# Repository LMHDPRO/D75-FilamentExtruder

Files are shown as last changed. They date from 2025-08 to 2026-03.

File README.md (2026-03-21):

<div align="center">

```
██████╗  ██████╗ ██╗   ██╗ ██████╗ ██╗      █████╗ ███████╗███╗███████╗
██╔══██╗██╔═══██╗██║   ██║██╔════╝ ██║     ██╔══██╗██╔════╝ ██║██╔════╝
██║  ██║██║   ██║██║   ██║██║  ███╗██║     ███████║███████╗╚██║███████╗
██║  ██║██║   ██║██║   ██║██║   ██║██║     ██╔══██║╚════██║ ██║╚════██║
██████╔╝╚██████╔╝╚██████╔╝╚██████╔╝███████╗██║  ██║███████║ ██║███████║
╚═════╝  ╚═════╝  ╚═════╝  ╚═════╝ ╚══════╝╚═╝  ╚═╝╚══════╝ ╚═╝╚══════╝
```

# Filament Extruder Controller

**ESP32 DualCore · FreeRTOS · PID Temperature · Dual TB6600**

*Reduce PP filament — 2.4 mm → 1.75 mm for 3D printing*

---







</div>

---

## ¿Qué es esto?

**Douglas75** es un controlador open-source para una extrusora de filamento, desarrollado originalmente en el marco de un **Practicum** universitario para reducir el diámetro de filamento fabricado artesanalmente. El diseño nació con polipropileno (PP) de **2.4 mm → 1.75 mm**, pero el sistema es compatible con cualquier tipo de filamento termoplástico que requiera un proceso de reducción controlada de diámetro.

El sistema corre en un **ESP32 con FreeRTOS dual-core** — un núcleo dedicado al control PID de temperatura y otro a la interfaz de usuario. Incluye un **panel de control Tkinter** para operación desde PC vía USB serial.

---

## Características

| | Función | Detalle |
|---|---|---|
| 🌡️ | Control temperatura | PID con NTC 100K genérico Ender3 (β = 3950) |
| 🔥 | Calefactor | MOSFET IRLZ44N, PWM 5 kHz vía LEDC |
| 💨 | Ventilador | MOSFET IRLZ44N, PWM proporcional AUTO o manual OFF |
| ⚙️ | Motores | 2× NEMA17 full-step, drivers TB6600, enable compartido |
| 🖥️ | LCD | I2C 20×4 @ 0x27, menú completo con encoder KY-040 |
| 💻 | GUI PC | Tkinter dark mode + gráfica temperatura en tiempo real |
| 🧵 | Estimación | Contador de filamento procesado (mm y gramos) |
| ⚡ | Arquitectura | FreeRTOS — Core 0: PID · Core 1: HMI |

---

## Hardware

### Bill of Materials (BOM)

| # | Categoría | Componente | Modelo / Especificación | Qty |
|:---:|---|---|---|:---:|
| 1 | 🧠 MCU | Microcontrolador | ESP32 Development Board | 1 |
| 2 | 🔥 Calefactor | Hotend completo | 40W 12V Ceramic Cartridge Heater + NTC 100K Thermistor | 1 |
| 3 | 🔩 Boquilla | Nozzle | MK8 0.4 mm Nozzle | 1 |
| 4 | ⚙️ Extrusión | Extrusor | Creality MK8 Extruder | 1 |
| 5 | ⚙️ Motor | Motor paso a paso | NEMA17 Stepper Motor | 2 |
| 6 | ⚙️ Driver | Driver motor | TB6600 Stepper Motor Driver | 2 |
| 7 | 🔧 Soporte | Montura motor | NEMA Motor Mount | 2 |
| 8 | 🖥️ Pantalla | Pantalla LCD | 20×4 LCD Screen I2C | 1 |
| 9 | 🎛️ Entrada | Encoder rotatorio | KY-040 Rotary Encoder | 1 |
| 10 | 🧵 Sensor | Sensor de filamento | Filament Runout Sensor | 1 |
| 11 | ⚡ Regulador | Regulador voltaje | L7805CV 5V Voltage Regulator (TO-220) | 1 |
| 12 | ⚡ MOSFET | MOSFET N-Channel | IRFL44N N-Channel MOSFET | 2 |
| 13 | 🔩 Rodamientos | Rodamiento | 608ZZ Bearing | 4 |
| 14 | 💨 Ventilador | Fan | 4010 Fan 12V | 1 |
| 15 | 🟫 PCB | Placa base | 15×15 cm Single-Sided Phenolic Board | 1 |
| 16 | 🔌 Conectores | Pin header | 36-pin Single Row Pin Header (2.54 mm) | 1 |
| 17 | 🔌 Conectores | Female header | 10-pin Female Header (2.54 mm) | 2 |
| 18 | 🔌 Conectores | Terminales | 2-Pin Green Screw Terminals | 6 |
| 19 | 🔋 Capacitores | Condensador electrolítico | 100 µF | 2 |
| 20 | 🔋 Capacitores | Condensador cerámico | 100 nF | 2 |
| 21 | 🔩 Tornillería | Tornillos Allen | M2, M3 & M4 Socket Head Screws (surtido) | — |

### Mapa de pines ESP32

| GPIO | Señal | Tipo |
|---|---|---|
| `18` | OUTA encoder (CLK) | Input interrupt |
| `19` | OUTB encoder (DT) | Input interrupt |
| `5` | SW encoder | Input PULLUP |
| `34` | Termistor NTC | ADC1_CH6 |
| `25` | MOSFET calefactor | PWM LEDC ch0 |
| `23` | MOSFET ventilador | PWM LEDC ch1 |
| `26` | STEP Motor 1 | Output |
| `27` | DIR Motor 1 | Output |
| `4` | STEP Motor 2 | Output |
| `2` | DIR Motor 2 | Output |
| `13` | EN_Driver | Output |
| `21` | SDA LCD | I2C |
| `22` | SCL LCD | I2C |

> ⚠️ **Pines prohibidos:** GPIO 0, 6–11 (flash interno), 12, 15

### Circuito divisor NTC

```
3.3V
 │
[4.7 KΩ]  ← R7 pull-up
 │
 ├──── GPIO34 ──────────────── net: Thermistor_GPIO34
 │
 ├──── 100 nF cerámico  ┐ en paralelo
 ├──── 10 µF electrolítico ┘
 │
[NTC 100K]  ← cable vía J3 terminal block
 │
GND
```

### Circuito calefactor

```
GPIO25 ──[10 Ω]──→ Gate IRLZ44N
                    Drain  → Calefactor DC 12V (−)
                    Source → GND

[10 KΩ] entre Gate y GND   ← pull-down, seguro durante boot
LED + [1.8 KΩ] en paralelo ← indicador visual de activación
```

### Alimentación dual USB + 12V

```
12V (fuente principal)
 ├── Buck LM2596 → 5V → VIN ESP32
 ├── TB6600 VMOT  (+ condensador 100 µF entre VMOT y GND)
 └── Calefactor DC (vía MOSFET)

USB-C ESP32 → PC  (serial Tkinter GUI)
✓ Coexistencia segura — diodo Schottky en DevKit aísla USB de VIN
```

---

## Menú LCD

```
ARRANQUE
  └── Splash 2s
        └── MENÚ PRINCIPAL
              ├── ► PRE-CALENTAR ──→ Calienta a 150 °C
              │                       Barra de progreso
              │                       Auto-arranca al llegar
              └── ► CONFIGURAR
                    ├── VELOCIDAD DRV 1   (0–300 RPM, paso 10)
                    ├── VELOCIDAD DRV 2   (0–300 RPM, paso 10)
                    ├── TEMPERATURA       (20–260 °C, paso 1)
                    └── VENTILADOR        (AUTO / OFF)

PANTALLA CORRIENDO:
  ┌────────────────────┐
  │ T:160.5C  SP:160C  │
  │ D1:100RPM D2:100RP │
  │ PWM:127   FAN:AUTO │
  │ CORRIENDO Lng=STOP │
  └────────────────────┘
```

**Controles encoder KY-040:**

| Acción | Función |
|---|---|
| Girar | Navegar menú / cambiar valor |
| Presión corta | Seleccionar / confirmar |
| Presión larga >700 ms | Volver / STOP de emergencia |

---

## Protocolo Serial

**115200 baud, 8N1**

### ESP32 → PC (cada 100 ms)

```
T:160.5,S:160,D1:100,D2:100,P:127,F:64,RUN:1
```

| Campo | Descripción |
|---|---|
| `T` | Temperatura real (°C) — o `ERR` si falla el sensor |
| `S` | Setpoint temperatura |
| `D1` / `D2` | RPM motores 1 y 2 |
| `P` | PWM calefactor (0–255) |
| `F` | PWM ventilador (0–255) |
| `RUN` | Estado extrusión `0`/`1` |

### PC → ESP32

| Comando | Descripción |
|---|---|
| `ST:165` | Cambiar setpoint temperatura |
| `SD1:100` | Cambiar RPM Motor 1 |
| `SD2:120` | Cambiar RPM Motor 2 |
| `SF:1` / `SF:0` | Ventilador AUTO / OFF |
| `RUN` | Iniciar extrusión |
| `STOP` | Detener extrusión |
| `JOG1:1` / `JOG1:0` | Motor 1 manual ON/OFF |
| `JOG2:1` / `JOG2:0` | Motor 2 manual ON/OFF |
| `EN:1` / `EN:0` | Habilitar / deshabilitar ambos TB6600 |

---

## Instalación

### Firmware ESP32

**1. Instalar PlatformIO:**

Instala la extensión [PlatformIO IDE](https://platformio.org/install/ide?install=vscode) para VS Code.

**2. Clonar y abrir el proyecto:**

```bash
git clone https://github.com/LMHDPRO/D75-FilamentExtruder.git
cd D75-FilamentExtruder
code .   # abrir en VS Code con PlatformIO
```

**3. Las dependencias se instalan automáticamente** desde `platformio.ini`:

```ini
[env:esp32dev]
platform  = espressif32
board     = esp32dev
framework = arduino
lib_deps  =
    mathertel/RotaryEncoder
    br3ttb/PID
    waspinator/AccelStepper
    marcoschwartz/LiquidCrystal_I2C
```

**4. Subir el firmware:**

Botón **Upload** (→) en la barra de PlatformIO, o:

```bash
pio run --target upload
```

> Si no entra en modo flash automáticamente, mantén presionado el botón **BOOT** del DevKit mientras sube.

**5. Verificar en Serial Monitor (115200 baud):**

```
T:25.3,S:160,D1:100,D2:100,P:0,F:0,RUN:0   ✓ Sensor OK
T:ERR,S:0,D1:0,D2:0,P:0,F:0,RUN:0          ✗ Revisar NTC o divisor
```

### GUI Python

```bash
pip install pyserial matplotlib
python extrusora_gui.py
```

---

## Arquitectura de software

```
ESP32 — FreeRTOS DualCore
│
├── Core 0  [prioridad 2]  taskPID
│    ├── Leer NTC (promedio 8 muestras)
│    ├── Calcular PID
│    ├── Escribir LEDC calefactor (0–255)
│    ├── Calcular PWM ventilador proporcional
│    └── Enviar telemetría serial cada 100 ms
│
└── Core 1  [prioridad 1]  taskHMI
     ├── Encoder KY-040 via interrupciones
     ├── Máquina de estados LCD (6 estados)
     ├── AccelStepper Motor 1 + Motor 2
     └── Parser comandos serial desde PC

Variables compartidas → protegidas con portMUX_TYPE
```

---

## Calibración

### Temperatura no coincide con la real

Cambiar `NTC_BETA` en `extrusora_esp32.ino`:

| Termistor | β |
|---|---|
| Genérico impresoras 3D (este proyecto) | **3950** |
| Semitec 104GT-2 | 4267 |
| EPCOS B57560G | 3988 |
| Marlin tabla 1 | 4388 |

### Motor gira al revés

```cpp
#define MOTOR_DIR  -1   →   #define MOTOR_DIR  1
```

### Estimación de filamento

Medir el diámetro del rodillo de arrastre con un vernier y actualizar en `extrusora_gui.py`:

```python
DRIVE_DIAM_MM = 11.0   # ← reemplazar con medición real
```

---

## Estructura del repositorio

```
D75-FilamentExtruder/
 ├── firmware/
 │    └── extrusora_esp32.ino      ← código ESP32
 ├── software/
 │    └── extrusora_gui.py         ← panel de control PC
 ├── hardware/
 │    ├── CircuitoESP32.kicad_sch  ← esquemático KiCad
 │    └── CircuitoESP32.kicad_pcb  ← PCB KiCad
 └── README.md
```

---

## Créditos

- [RotaryEncoder](https://github.com/mathertel/RotaryEncoder) — Matthias Hertel
- [Arduino PID Library](https://github.com/br3ttb/Arduino-PID-Library) — Brett Beauregard
- [AccelStepper](https://www.airspayce.com/mikem/arduino/AccelStepper/) — Mike McCauley
- [LiquidCrystal_I2C](https://github.com/marcoschwartz/LiquidCrystal_I2C) — Frank de Brabander

---

## Equipo

<div align="center">

*Proyecto desarrollado en la* **Universidad Anáhuac Mayab** *— Mérida, Yucatán*

<br>

| | Nombre | |
|:---:|:---|:---:|
| 🧑‍💻 | **Skyler Schenck** |  |
| 🧑‍💻 | **Darian Cuellar** |  |
| 🧑‍💻 | **José Pardiñaz** |  |
| 🧑‍💻 | **Douglas Fuentes** |  |
| 🧑‍🔬 | **Gerardo Alonzo** |  |
| 🧑‍🔬 | **Andrés Oliva** |  |

<br>



</div>

---

## Apoya el proyecto

Este proyecto es **open-source bajo licencia MIT** — puedes usarlo, modificarlo y distribuirlo libremente. Si te fue útil y quieres apoyar al creador, puedes conseguir los archivos 3D del modelo físico de la extrusora en Cults3D a precio libre:

<div align="center">



*Los archivos de código son y serán siempre gratuitos. El modelo 3D está disponible en Cults a precio libre — cualquier contribución es bienvenida y apoya el desarrollo continuo.*

</div>

---

## Licencia

MIT License — úsalo, modifícalo y distribúyelo libremente.

---

<div align="center">
<sub>Douglas75 Project · ESP32_Experimental · Made with ☕ in Mérida, MX</sub>
</div>

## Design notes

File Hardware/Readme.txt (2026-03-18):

KICAD 9.0

CREATED & DESIGNED BY JOSÉ PARDIÑAZ AND DOUGLAS FUENTES :)

V2. DARIAN CUELLAR

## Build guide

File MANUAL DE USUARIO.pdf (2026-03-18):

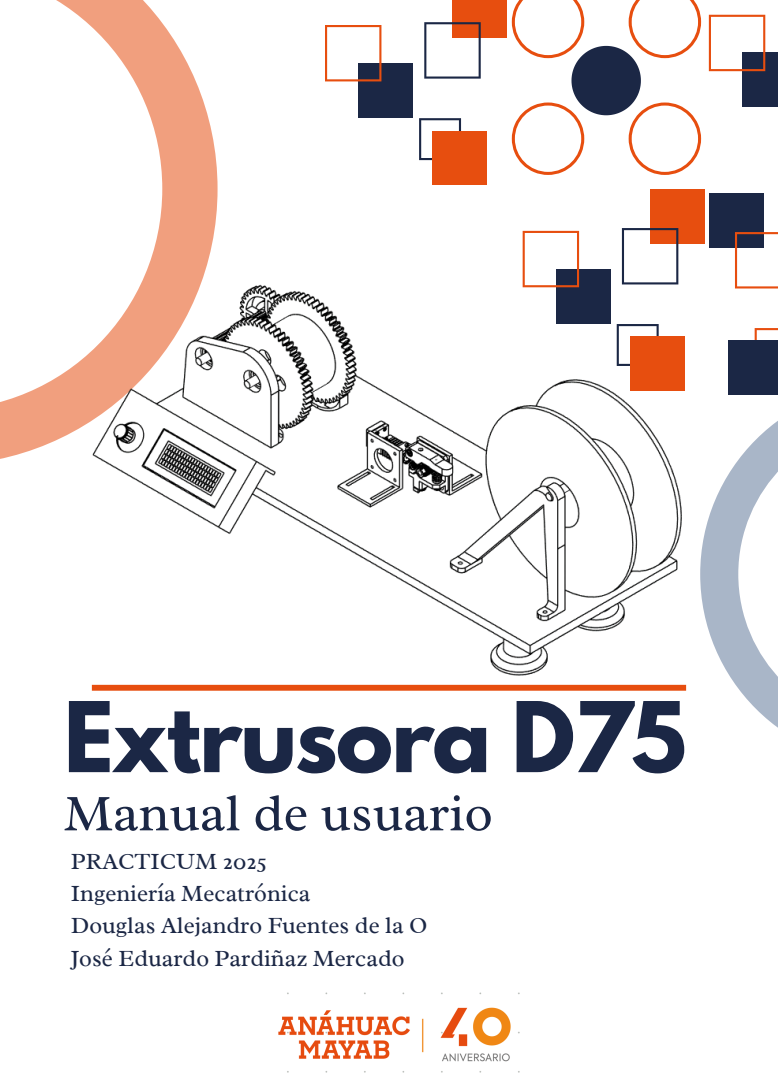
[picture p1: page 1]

Extrusora D75
Manual de usuario

PRACTICUM 2025
Ingeniería Mecatrónica
Douglas Alejandro Fuentes de la O
José Eduardo Pardiñaz Mercado

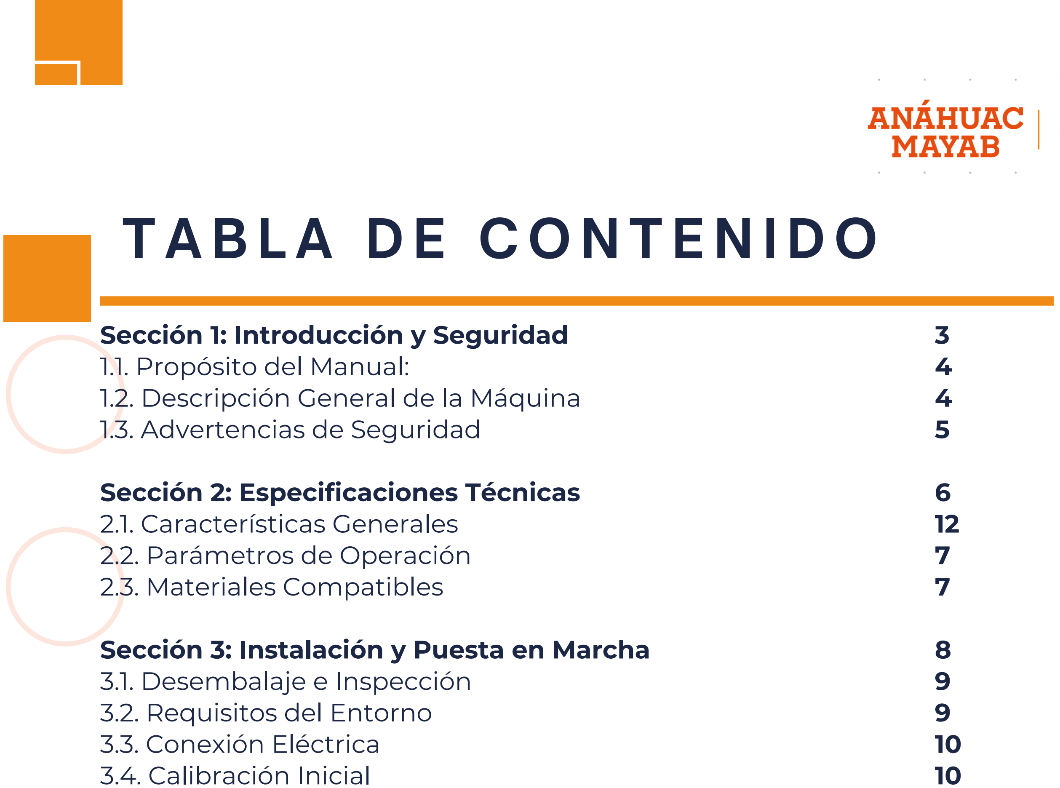
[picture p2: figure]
Sección 1: Introducción y Seguridad 1.1. Propósito del Manual: 1.2. Descripción General de la Máquina 1.3. Advertencias de Seguridad; Sección 2: Especificaciones Técnicas 2.1. Características Generales 2.2. Parámetros de Operación 2.3. Materiales Compatibles; 3.1. Desembalaje e Inspección 3.2. Requisitos del Entorno 3.3. Conexión Eléctrica

Sección 3: Instalación y Puesta en Marcha

3.4. Calibración Inicial

Sección 4: Componentes y Panel de Control
4.1. Diagrama General
4.2. Descripción del Panel de Control

Sección 5: Guía de Operación
5.1. Preparación del Material
5.2. Procedimiento de Encendido
5.3. Proceso de Extrusión
5.4. Procedimiento de Apagado y Purga

Sección 6: Mantenimiento y Limpieza
6.1. Programa de Mantenimiento Preventivo
6.2. Procedimientos de Limpieza
6.3. Procedimientos de Mantenimiento

Sección 7: Solución de Problemas
7.1. Tabla de Fallos Comunes

Sección 8: Anexos Técnicos
A. Diagrama Eléctrico
B. Diseño de PCB
C. Explosión y lista de componentes
D. Firmware del sistema
E. Glosarios de términos
F. Archivos STL

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
# INTRODUCCIÓN Y SEGURIDAD

# S E C C I Ó N 1

## Esta sección inicial presenta la Extrusora D75, explicando

su propósito y las capacidades de reciclaje de filamento.

## Fundamentalmente, establece las advertencias de seguridad más importantes, detallando los riesgos de quemaduras por altas temperaturas, atrapamiento por partes móviles y peligros eléctricos, además de especificar el equipo de protección personal necesario para operar la

máquina de forma segura.

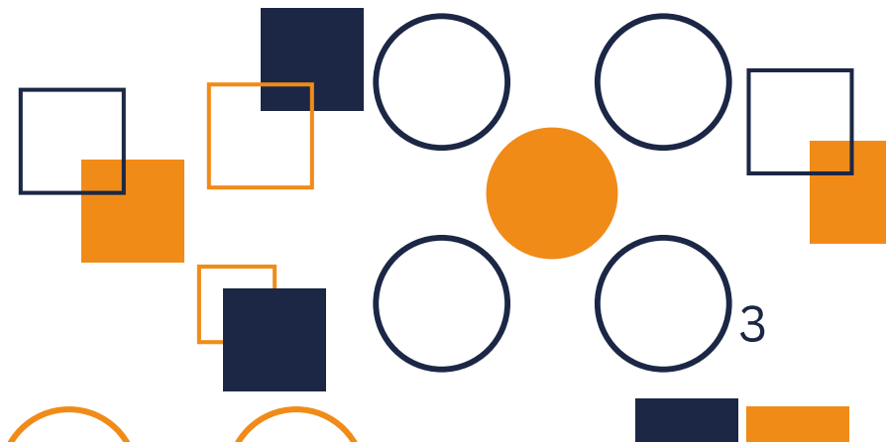
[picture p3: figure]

# 1.1. Propósito de este Manual

# 1.2. Descripción General de la Máquina

Bienvenido a la Extrusora D75. Este manual le proporcionará toda la información necesaria para instalar, operar y mantener su máquina de forma segura y eficiente. Ha sido redactado para guiarlo a través de todas las capacidades del equipo.
Es fundamental leer este documento en su totalidad antes de energizar u operar la extrusora. Guarde este manual en un lugar accesible para futuras consultas.

La Extrusora D75 es una máquina de extrusión de filamento diseñada para ser una herramienta versátil en entornos académicos e de investigación. Su propósito es transformar tramos de plástico en un filamento de alta calidad con un diámetro nominal de 1.75 mm.
Desarrollada con un enfoque en la accesibilidad y la personalización, su construcción de bajo costo y diseño cómodo la convierten en una plataforma ideal para:
Estudiantes y educadores: Para el aprendizaje práctico sobre polímeros y procesos de reciclaje.
Proyectos de investigación: Permitiendo la experimentación con una amplia gama de termoplásticos.
Profesionales y talleres: Para reutilizar material de desecho (impresiones fallidas, soportes) y reducir costos operativos.

Aunque ha sido probada exitosamente con materiales como PET y PP, su diseño permite trabajar con un amplio espectro de polímeros que se ajusten a su rango de temperatura.

# 1.3. Advertencias de Seguridad

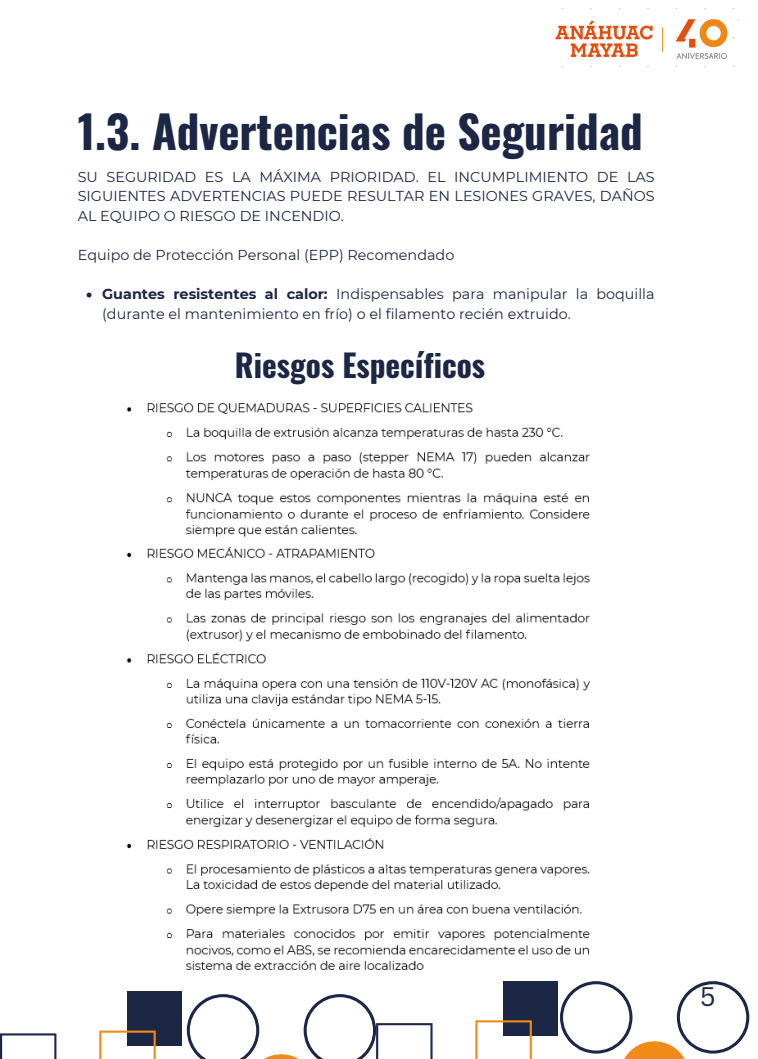
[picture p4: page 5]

SU SEGURIDAD ES LA MÁXIMA PRIORIDAD. EL INCUMPLIMIENTO DE LAS
SIGUIENTES ADVERTENCIAS PUEDE RESULTAR EN LESIONES GRAVES, DAÑOS
AL EQUIPO O RIESGO DE INCENDIO.

Equipo de Protección Personal (EPP) Recomendado

Guantes resistentes al calor: Indispensables para manipular la boquilla
(durante el mantenimiento en frío) o el filamento recién extruido.
Riesgos Específicos

# ESPECIFICACIONES TÉCNICAS

# S E C C I Ó N 2

Aquí se encuentra la ficha técnica completa de la máquina. Este apartado cuantifica las características del equipo, incluyendo sus dimensiones físicas y peso , los parámetros eléctricos como el voltaje de operación y el consumo de potencia , su rendimiento de extrusión con la velocidad y la tolerancia de diámetro , y la lista de

materiales plásticos compatibles que puede procesar.

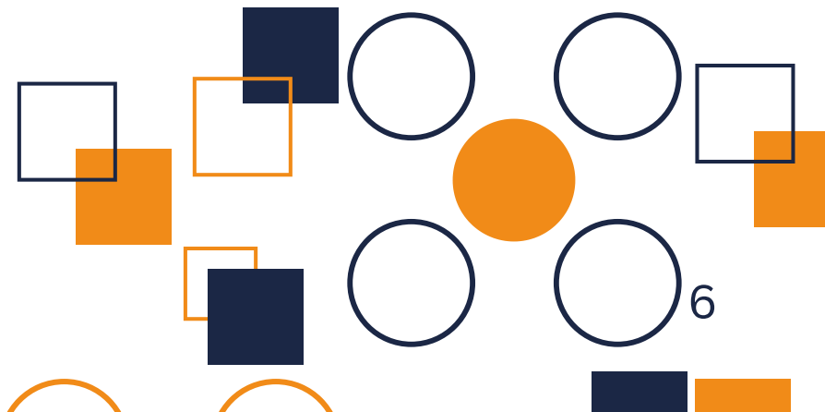
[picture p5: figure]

# 2.1. Características Generales

# 2.3. Materiales Compatibles

Dimensiones (L × An × Al): 540 mm × 155 mm × 435 mm
Peso neto: 1.86 kg
Principio de extrusión: Extrusión térmica mediante sistema de impulsión por engranes.
Sistema de extrusión: Basado en el mecanismo de extrusión de la Creality Ender 3 v1, adaptado para la alimentación y fusión de filamento termoplástico.

El diseño de la Extrusora D75 permite trabajar con una variedad de termoplásticos. A continuación se listan los materiales probados y los potencialmente compatibles.
Materiales Verificados:
PET (Tereftalato de polietileno)
PP (Polipropileno)
Materiales Teóricamente Compatibles:
PLA (Ácido poliláctico)
PETG (Tereftalato de polietileno modificado con glicol)
TPU (Poliuretano termoplástico y otros elastómeros)
HDPE / LDPE (Polietileno de alta y baja densidad)
Nota Importante: La compatibilidad teórica se basa en el rango de temperatura de la máquina. El éxito de la extrusión con estos materiales dependerá de la correcta configuración de los parámetros.

# 2.2. Parámetros de Operación

Eléctricos

Tensión de Alimentación: 110V-120V AC (monofásica). Sistema de Calentamiento: Cartucho calefactor de 12V, 40W. Consumo Máximo de Potencia: 56W

Rendimiento

Temperatura Máxima de Operación: 230 °C (en la boquilla). Diámetro Nominal del Filamento: 1.75 mm
Tolerancia de Diámetro: ±0.04 mm
Velocidad de Extrusión (aprox.): 0.5 metros/minuto.

# INSTALACIÓN Y PUESTA EN MARCHA

# S E C C I Ó N 3

Esta es la guía para el primer uso, que detalla los pasos para preparar la máquina desde que sale de la caja. Cubre el desembalaje, la inspección inicial, los requisitos del entorno de trabajo como la necesidad de una superficie nivelada y ventilada, y el procedimiento correcto para la conexión eléctrica y el encendido inicial seguro del

sistema.

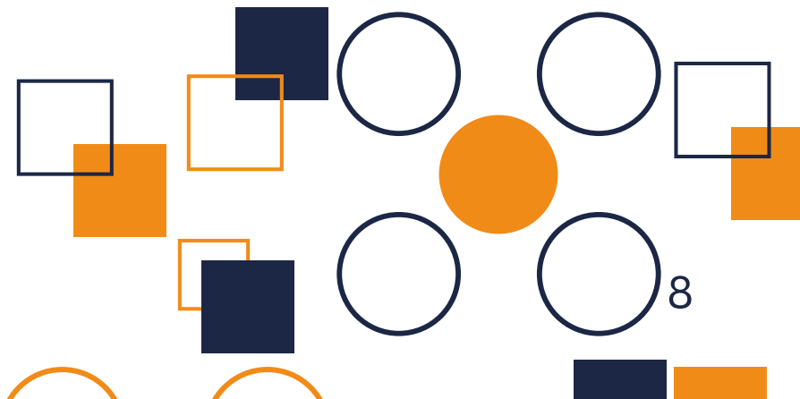
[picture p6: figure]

# 3.1. Desembalaje e Inspección

Inspección visual: Revise la máquina en busca de posibles daños ocurridos durante el transporte. Asegúrese de que todos los componentes estén firmes y en su lugar.
Contenido del paquete:
Unidad principal de la Extrusora D75.
Juego de boquillas de extrusión adicionales.
Cable de alimentación.
Portacarrete.
Montaje del Portacarrete: Fije el portacarrete en su posición designada. Asegúrese de que quede firme y estable para soportar el peso de una bobina de material.

# 3.2. Requisitos del Entorno de Trabajo

Seleccionar un lugar adecuado es clave para la seguridad y la calidad de la extrusión.
Superficie de Trabajo: Coloque la máquina sobre una superficie firme, estable y perfectamente nivelada.
Condiciones Ambientales:
Instale la máquina en un lugar seco y con buena ventilación. Evite a toda costa los ambientes húmedos.
Mantenga la máquina alejada de la luz solar directa y de otras fuentes de calor. El calor excesivo puede afectar tanto a la electrónica como a los materiales (especialmente PLA).
¡Peligro de Incendio! Opere la máquina lejos de cualquier material inflamable (líquidos, gases, papeles, etc.).
Espacio de Operación: Deje un área de seguridad de al menos 20 cm de espacio libre alrededor de todos los lados de la máquina para garantizar una correcta ventilación y un acceso sin obstrucciones.

# 3.3. Conexión Eléctrica

ADVERTENCIA: Antes de conectar el cable de alimentación, verifique siempre que el interruptor de encendido principal se encuentre en la posición de APAGADO (OFF o 'O').

1.Conecte el extremo hembra del cable de alimentación a la toma de corriente de la Extrusora D75.
2.Conecte el extremo macho del cable a un tomacorriente de pared de 110V-120V con conexión a tierra.

# 3.4. Preparación y Puesta en Marcha Inicial

Este procedimiento asegura que la máquina está lista para operar antes de introducir material.
1.Encendido y Verificación:
Una vez conectada, accione el interruptor principal a la posición de ENCENDIDO (ON o 'I').
Observe la pantalla o los indicadores. Espere a que el firmware se inicialice correctamente.
2.Inspección Mecánica:
Con la máquina encendida pero sin operar, verifique manualmente que los motores paso a paso (steppers) y los engranajes puedan moverse libremente y que no haya obstrucciones en los mecanismos. 3.Colocación del Carrete de Material:
Coloque el carrete con el material que desea extruir (pellets o triturado) en el portacarrete.
4.Preparación para la Extrusión:
Una vez que el proceso de extrusión comience y el filamento empiece a salir por la boquilla, deberá guiarlo manualmente a través del sensor de filamento (si aplica) y hacia el sistema de embobinado.

Su Extrusora D75 ya está instalada y lista para la siguiente fase: la Operación.

# COMPONENTES Y PANEL DE CONTROL

# S E C C I Ó N 4

Esta sección funciona como un mapa anatómico de la extrusora. A través de diagramas y listas, identifica cada componente físico principal, desde el sistema de tracción hasta el cabezal de extrusión. Además, explica a fondo el panel de control, detallando la función de cada botón, el significado de los indicadores LED y la información que se

muestra en la pantalla LCD durante la operación.

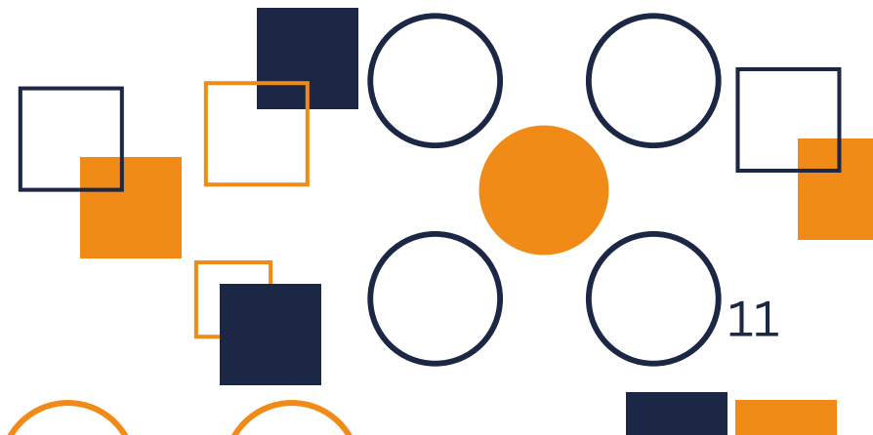
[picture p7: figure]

# 4.1. Diagrama y Lista de Componentes

Panel de Control: Contiene la pantalla, los controles y los indicadores para operar la máquina.
Sistema de Tracción (Feeder): Conjunto de engranajes y motor paso a paso que empuja el filamento de entrada hacia el cabezal de extrusión. Portacarrete de Entrada: Soporte para la bobina de filamento que alimentará la máquina.
Cabezal de Extrusión (Hotend): Calienta el filamento hasta su punto de fusión. Aquí se alojan el cartucho calefactor, el termistor y la boquilla. Portacarrete de Salida (Embobinador): Soporte para el carrete vacío donde se enrollará el nuevo filamento de 1.75 mm.
Base de Montaje: Estructura principal que soporta todos los componentes.
Controladores de Motor (Drivers): Módulos (TB6600) que gestionan la potencia y el movimiento de los motores paso a paso.

# 4.2. Panel de Control

(A) Pantalla LCD 20x4

Muestra en tiempo real los parámetros de operación de la máquina. La información que presenta es:
Temperatura Actual: La temperatura medida por el termistor en el cabezal de extrusión (°C).
Temperatura Objetivo: La temperatura que se ha configurado como meta (°C).
Velocidad Actual: La velocidad a la que opera el motor de tracción (mm/s). Velocidad Objetivo: La velocidad que se ha configurado como meta (mm/s).
(B) Perilla de Control (Encoder KY-040)

Es el control principal para ajustar los parámetros:
Girar la perilla: Modifica el valor seleccionado (temperatura o velocidad). Presionar la perilla: Cambia entre el modo de ajuste de Temperatura (50 °C a 230 °C) y el modo de ajuste de Velocidad (0 a 100 mm/s).

(C) Botones de Operación

Botón START: Inicia el proceso de extrusión. Activa el calentador para que alcance la temperatura objetivo y, una vez alcanzada, enciende el motor a la velocidad configurada.
Botón MOTOR OFF: Detiene únicamente el motor de tracción. Es útil para pausar la alimentación de filamento sin apagar el sistema de calentamiento.
Botón de STOP: Botón de parada de emergencia. Detiene inmediatamente todas las funciones de la máquina (motor y calentador).
(D) Indicadores Luminosos (LEDs)

Proporcionan información visual rápida sobre el estado del sistema:
LED 1 (Calentador): Se enciende para indicar que el cartucho calefactor está activo y recibiendo energía para calentar o mantener la temperatura. LED 2 (Encendido/Sistema): Indica que la máquina está encendida y la placa de control (PCB) está energizada.

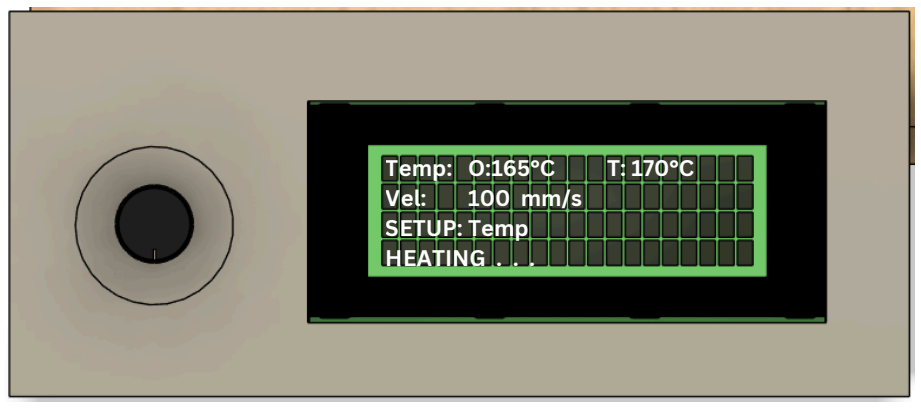
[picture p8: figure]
Temp: O:165°C; Vel:; SETUP: Temp HEATING . . .
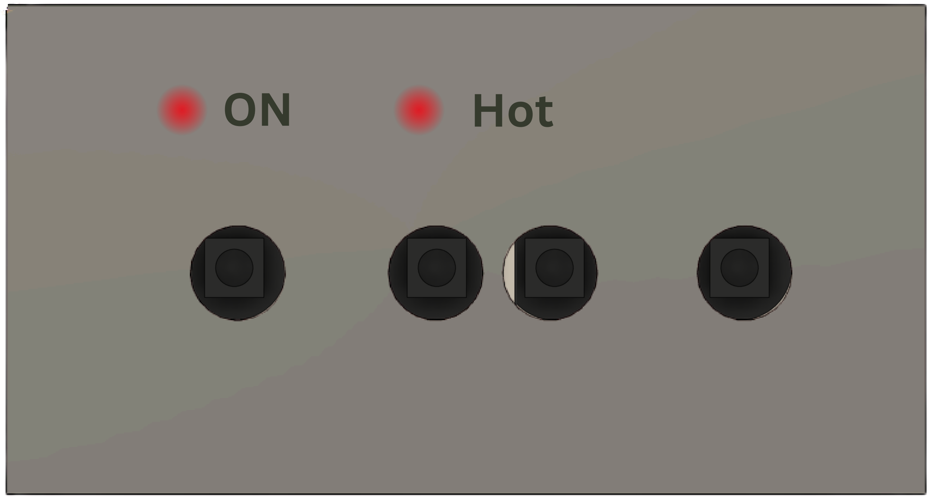
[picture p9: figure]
Hot

# GUÍA DE OPERACIÓN

# S E C C I Ó N 5

## Este es el corazón del manual para el usuario, explicando el flujo de trabajo completo para usar la máquina en el día a día. Detalla la secuencia de pasos a seguir: la preparación y carga del filamento, la configuración de los parámetros de temperatura y velocidad, el inicio del proceso de

extrusión, el monitoreo del filamento resultante y,

## finalmente, el procedimiento correcto para detener la

máquina y apagarla de forma segura.

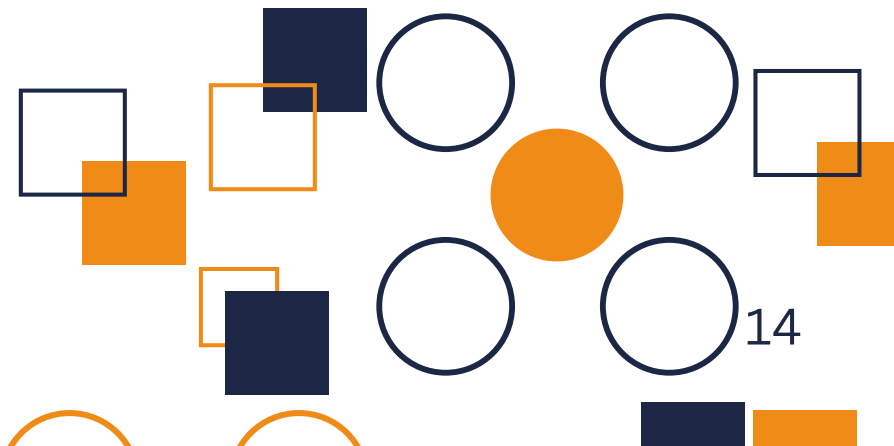
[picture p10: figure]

# 5.1. Preparación del Filamento de Entrada

La calidad del filamento de entrada impacta directamente en el resultado final.
Inspección del Material: Antes de comenzar, asegúrese de que el filamento que va a introducir esté limpio, seco y libre de enredos en su bobina. Un material húmedo o sucio puede provocar una extrusión inconsistente y porosa.
Verificación de Integridad: Revise que el filamento no presente quiebres, nudos o dobleces pronunciados que puedan causar un atasco en el sistema.
Carga en el Sistema de Tracción (Feeder):
Coloque la bobina de filamento de entrada en su portacarrete, asegurándose de que pueda girar libremente.
Presione la palanca del resorte del extrusor para liberar la tensión de los engranajes.
Inserte la punta del filamento a través del mecanismo hasta que sienta que hace tope.
Suelte la palanca del resorte. El filamento debe quedar firmemente sujeto por los engranajes.

# 5.2. Encendido y Configuración de Parámetros

Con la máquina encendida, configure los parámetros de extrusión según el material a utilizar.
1.Ajuste de Temperatura y Velocidad:
Utilice la perilla de control para establecer los valores deseados.
Gire la perilla para aumentar o disminuir el valor.
Presione la perilla para alternar entre el modo de ajuste de Temperatura (°C) y el de Velocidad (mm/s).

Tabla de Parámetros Recomendados
Los siguientes valores son un punto de partida. Es posible que requiera afinarlos según las características específicas de su material.

# 5.3. Proceso de Extrusión

1.Inicio del Proceso: Una vez configurados los parámetros, presione el botón START. La máquina ejecutará la siguiente secuencia automática: a.El LED indicador del calentador se encenderá.
b.La máquina comenzará a calentar el cabezal de extrusión. En la pantalla, podrá ver cómo la "Temperatura Actual" aumenta hasta igualar la "Temperatura Objetivo"
c.Una vez alcanzada la temperatura, el motor de tracción se activará automáticamente a la velocidad configurada.
2.Manejo del Filamento Extruido:
a.Observe la boquilla. En pocos segundos, el nuevo filamento de 1.75 mm comenzará a salir.
b.Con guantes resistentes al calor, tome con cuidado la punta del filamento y guíela hacia el carrete de salida vacío. Fíjelo al carrete (puede usar los orificios del mismo o un trozo de cinta adhesiva). 3.Monitoreo y Ajustes en Tiempo Real:
4.Durante todo el proceso, es crucial monitorear la operación. Observe la consistencia y el diámetro del filamento que se está produciendo.
5.Si el resultado no es óptimo, puede realizar ajustes en tiempo real utilizando la perilla de control. Por ejemplo:
i.Si el filamento se ve demasiado delgado, intente reducir la velocidad.
ii.Si la superficie es rugosa, pruebe a ajustar ligeramente la temperatura.
6.Los cambios se aplicarán de forma instantánea.

# 5.4. Procedimiento de Apagado y Limpieza Final

Siga esta secuencia para detener la operación de forma segura y dejar la máquina lista para el siguiente uso.
1.Detener la Operación: Cuando el filamento de entrada se haya agotado o desee finalizar el trabajo, presione el botón de STOP. 2.Enfriamiento Automático: Al presionar STOP, el motor se detendrá y el sistema de calentamiento se desactivará. La máquina entrará en un modo de enfriamiento pasivo.
3.Apagado Seguro: No apague la máquina inmediatamente. Espere y observe la pantalla hasta que la temperatura de la boquilla haya descendido por debajo de los 50 °C. Esto previene la degradación del plástico en el hotend.
4.Corte de Energía: Una vez que la temperatura sea segura, apague la máquina utilizando el interruptor basculante principal.
5.Limpieza y Retiro de Filamento: Es una buena práctica verificar que no queden restos de material acumulados en la punta de la boquilla. Si va a guardar la máquina, retire el filamento sobrante del sistema de tracción para evitar que se quede pegado o se quiebre en el interior.

# MANTENIMIENTO Y LIMPIEZA

# S E C C I Ó N 6

## Este apartado se enfoca en prolongar la vida útil y el rendimiento óptimo de la máquina. Establece un programa de mantenimiento preventivo con tareas diarias, semanales y mensuales, como la limpieza de la boquilla, la revisión de tornillería y la lubricación de

engranajes. | También | incluye | instrucciones | para

## procedimientos más avanzados, como la solución de

atascos de material.

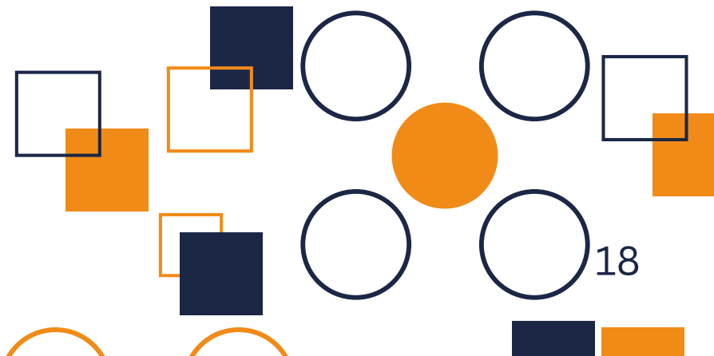
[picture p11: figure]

# 6.1. Herramientas y Suministros Necesarios

Para realizar el mantenimiento, se recomienda tener a mano las siguientes herramientas:
Cepillo de cerdas suaves (latón o nylon).
Juego de llaves Allen (tamaños M3 y M4).
Pinzas de punta fina.
Llave de tubo o la herramienta adecuada para remover la boquilla (nozzle). Paños de microfibra limpios y secos.
Grasa de litio blanca o lubricante similar para engranajes.

# 6.2. Programa de Mantenimiento Preventivo

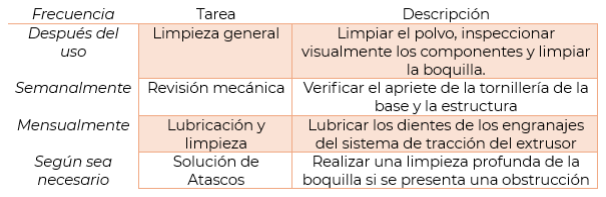
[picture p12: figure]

Nota Operacional Importante Límites de Uso Continuo: Para prevenir el sobrecalentamiento de los motores y la electrónica, se recomienda no operar la máquina por más de 6 horas continuas. Después de un ciclo de trabajo prolongado, apague la máquina y permita que se enfríe completamente antes de iniciar un nuevo ciclo.

# 6.3. Procedimientos de Mantenimiento

Después de Cada Uso (Diario)
1.Limpieza de Superficies: Con un paño seco o un cepillo suave, retire el polvo y cualquier residuo de plástico de la base y la estructura de la máquina.
2.Inspección Visual: Eche un vistazo rápido a los engranajes del sistema de tracción para asegurarse de que no haya filamento triturado acumulado entre los dientes.
3.Limpieza de la Boquilla: Mientras la boquilla aún esté caliente (con precaución y usando guantes), utilice un cepillo de cerdas de latón para limpiar suavemente cualquier excedente de plástico solidificado en el exterior de la punta.

Semanalmente (o cada 20 horas de uso)
Revisión de Tornillería: Con las llaves Allen correspondientes, verifique suavemente que los tornillos que sujetan los componentes a la base de madera estén firmes. No los apriete en exceso para no dañar la madera.

Mensualmente (o cada 80 horas de uso)
Lubricación de Engranajes: Aplique una pequeña cantidad de grasa de litio blanca en los dientes de los engranajes del sistema de tracción. Mueva manualmente los engranajes para distribuir el lubricante de manera uniforme. Esto reduce el desgaste y el ruido.

# 6.4. Procedimientos de Limpieza Avanzada

Solución de Atascos en la Boquilla (Método "Cold Pull")

Si el filamento no fluye correctamente, puede haber una obstrucción. El método de "tirón en frío" es muy efectivo para limpiarla.

1.Caliente el hotend a la temperatura de trabajo del último material utilizado (ej. 165 °C para PP).
2.Empuje manualmente un trozo del mismo filamento a través del sistema de tracción hasta que fluya un poco por la boquilla.
3.Reduzca la temperatura objetivo a unos 80-90 °C (por debajo del punto de fusión pero aún maleable).
4.Una vez que la temperatura se estabilice, tire del filamento hacia atrás de forma rápida y firme. Debería salir llevándose consigo la suciedad o el material quemado del interior.
5.Repita el proceso si es necesario hasta que la punta del filamento extraído salga limpia.

# SOLUCIÓN DE PROBLEMAS

# S E C C I Ó N 7

# (Troubleshooting)

Esta es la guía de diagnóstico y reparación para el usuario.

## Se presenta en formato de tabla y aborda los problemas

más comunes que pueden surgir durante la operación,

## como un diámetro de filamento inconsistente, ruidos en el motor o fallos de calentamiento. Para cada problema, se describe la causa más probable y se ofrece una solución

práctica y probada.

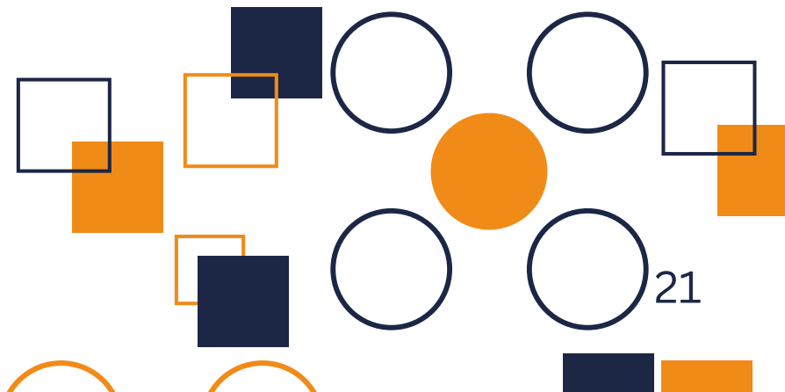
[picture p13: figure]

# 7.1 Troubleshooting

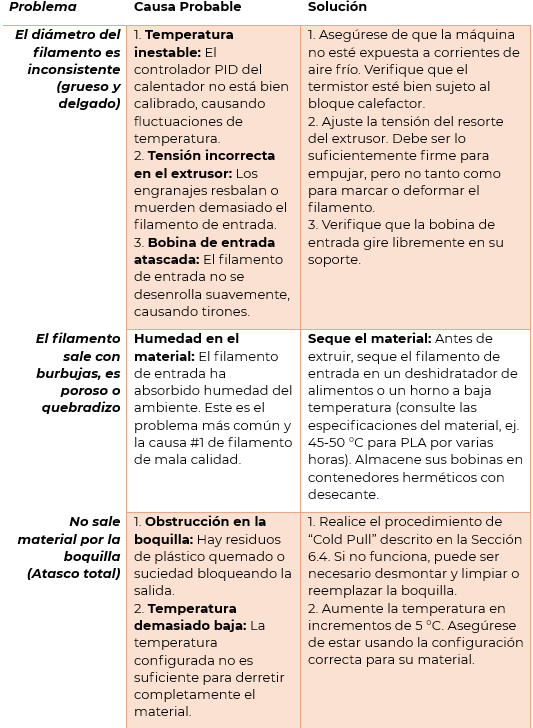
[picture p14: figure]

# 7.1 Troubleshooting

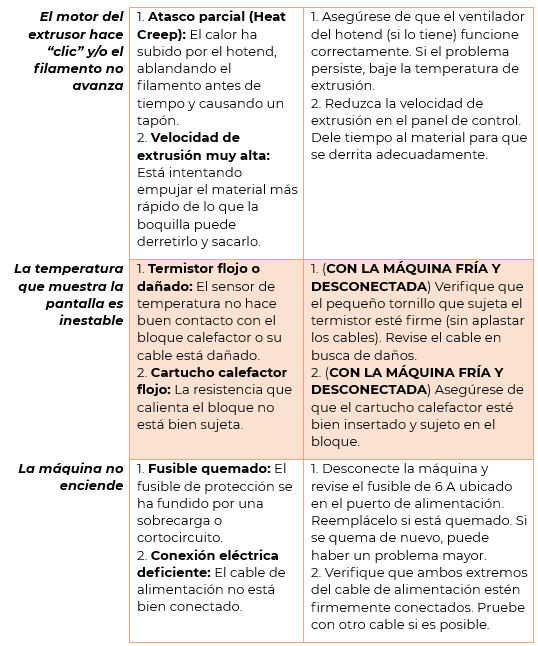
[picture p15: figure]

# ANEXOS

# S E C C I Ó N 8

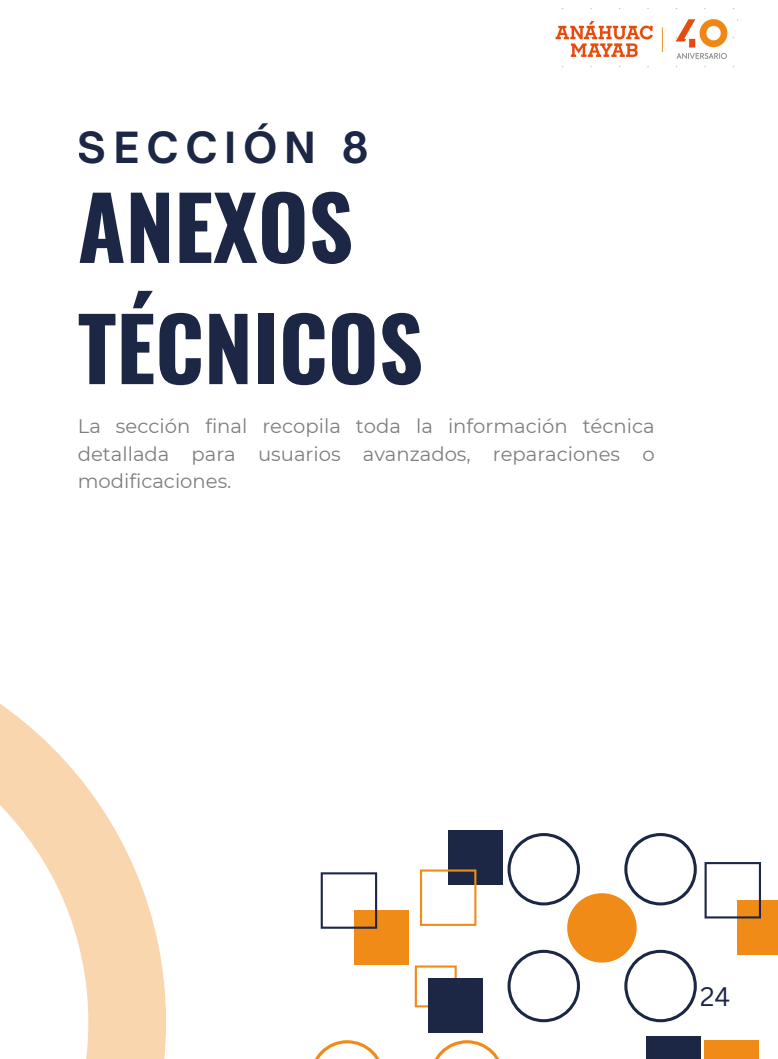
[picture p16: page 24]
TÉCNICOS

La sección final recopila toda la información técnica
detallada para usuarios avanzados, reparaciones o
modificaciones.

# Anexo A: Diagrama Eléctrico

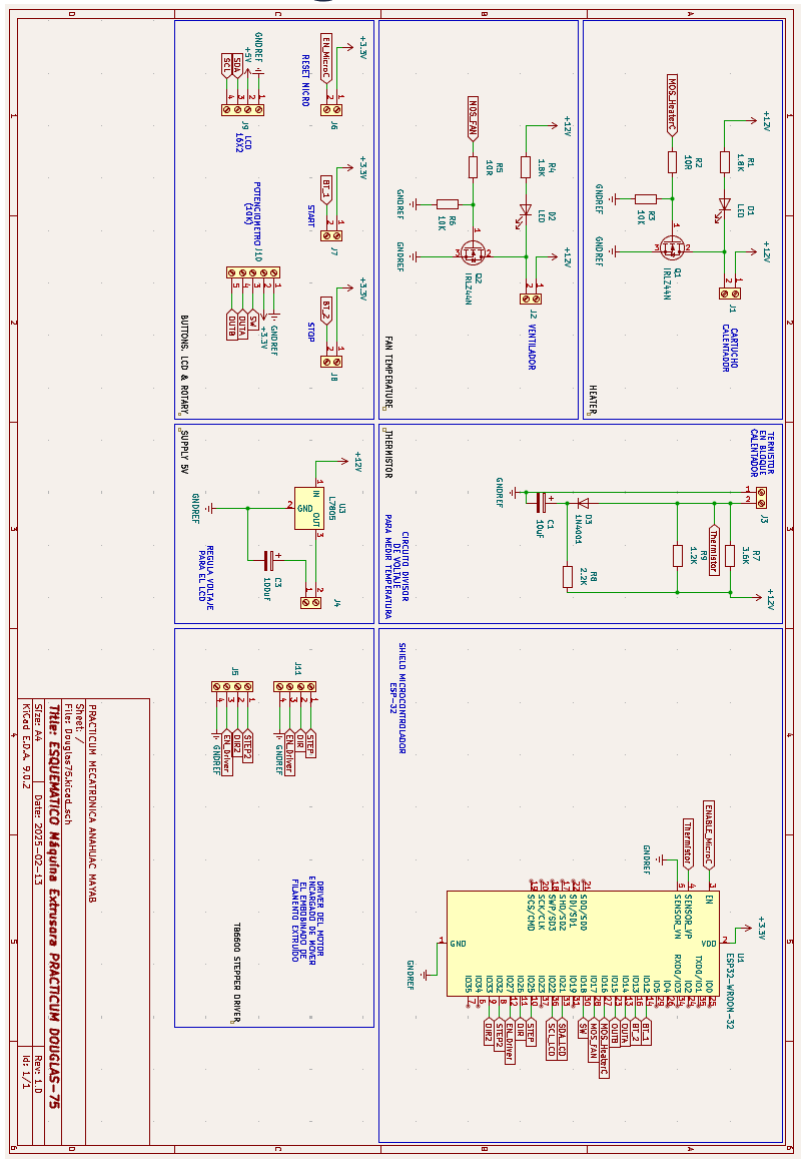
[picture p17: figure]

# Anexo B: Diseño de Placa de Circuito Impreso (PCB)

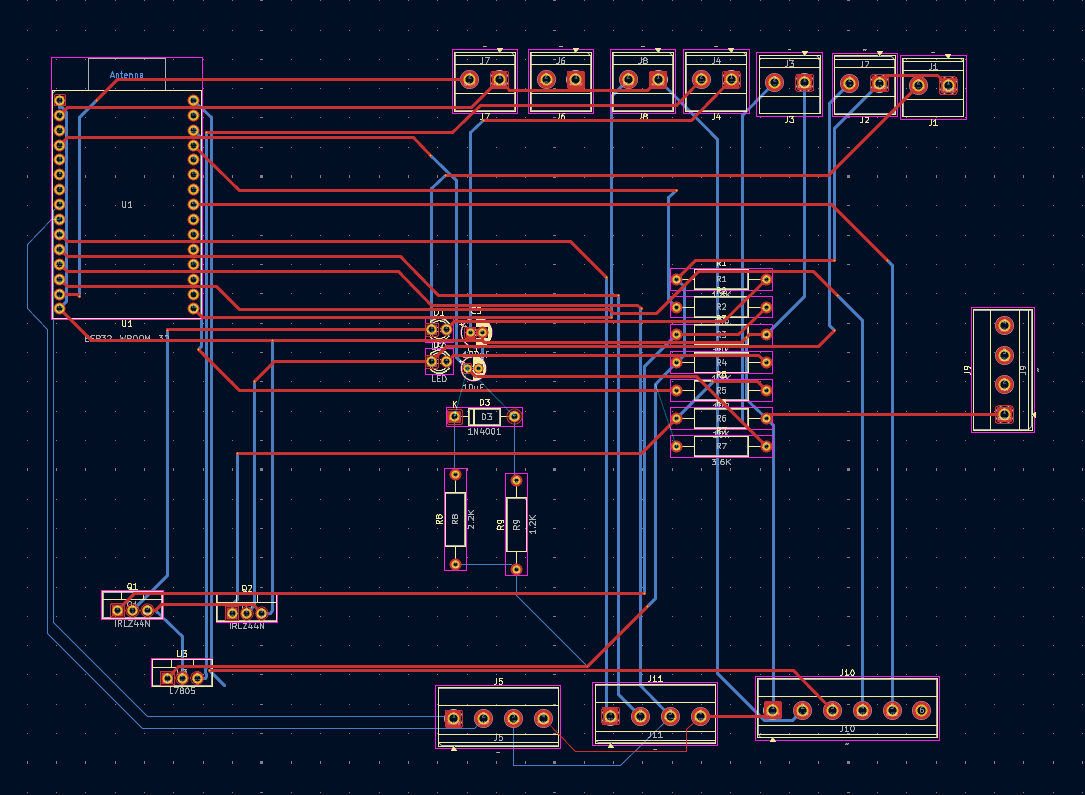
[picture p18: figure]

# Anexo C: Despiece Mecánico y Lista de Partes (BOM)

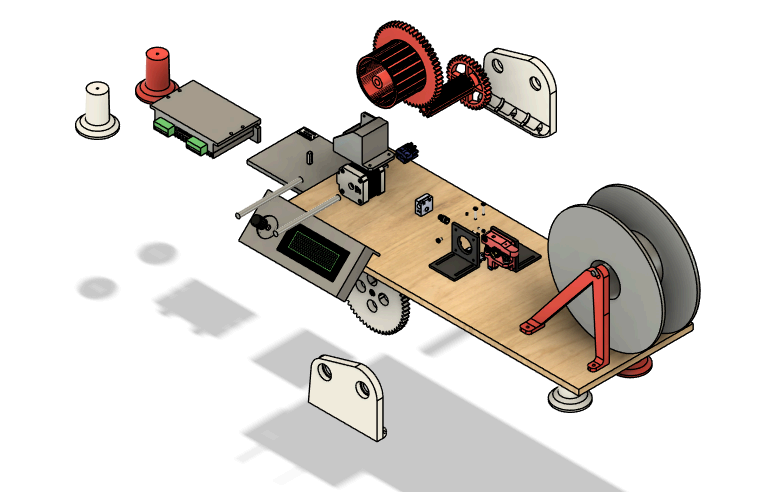
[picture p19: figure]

# Anexo C: Despiece Mecánico y Lista de Partes (BOM)

# Anexo C: Despiece Mecánico y Lista de Partes (BOM)

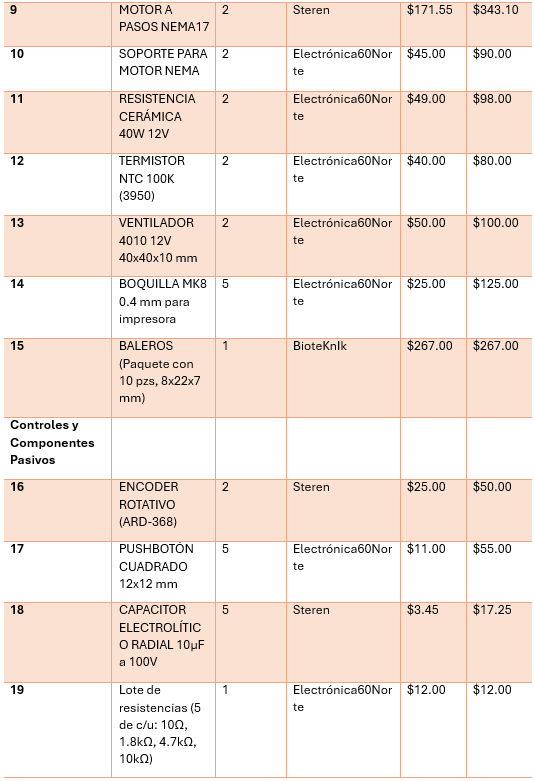
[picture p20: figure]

# Anexo C: Despiece Mecánico y Lista de Partes (BOM)

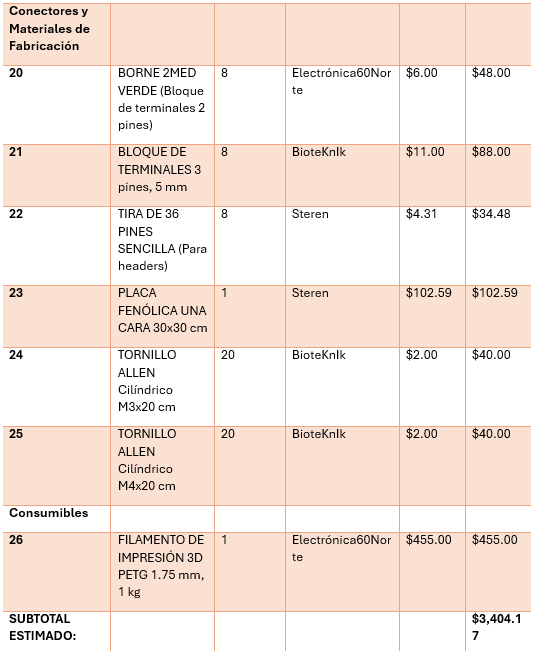
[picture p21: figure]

# Anexo D: Información del Firmware

El funcionamiento de la Extrusora D75 es controlado por un firmware personalizado, diseñado específicamente para este hardware, garantizando una operación estable y precisa.

Microcontrolador: El cerebro de la máquina es un módulo ESP32-WROOM-32.

Desarrollo: El firmware es de código personalizado y utiliza las siguientes librerías principales para su funcionamiento: LiquidCrystal_I2C.h - Para la comunicación con la pantalla LCD. RotaryEncoder.h - Para la gestión de la perilla de control. AccelStepper.h - Para el control avanzado de los motores paso a paso.
PID_v1.h - Para el control preciso y estable de la temperatura (PID). Wire.h - Para la comunicación I2C con la pantalla.

Código Fuente y Más Detalles: Para acceder a información más detallada sobre el firmware y posibles actualizaciones, escanee el siguiente código QR.

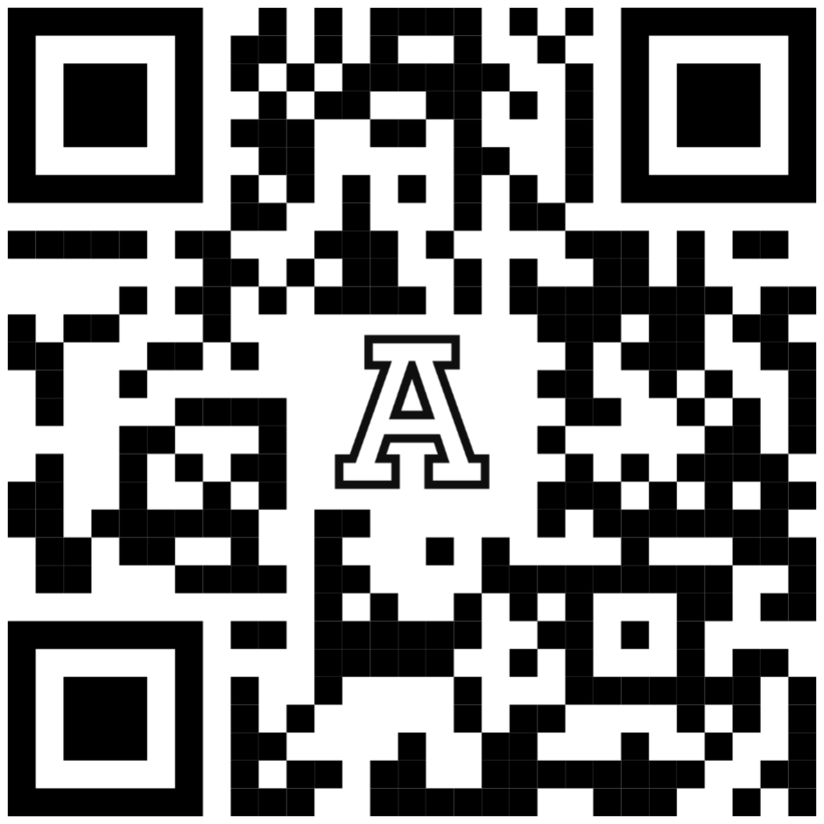
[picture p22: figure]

# O ingresa a

# Anexo E: Glosario de Términos

Cartucho calefactor: Elemento electrónico conocido como resistencia de alta potencia que permite calentar objetos.
Cold Pull (Tirón en Frío): Técnica de limpieza del hotend que consiste en retirar el filamento a una temperatura intermedia para arrastrar impurezas y material quemado.
Creality: Empresa china dedicada a máquinas CNC e impresión 3D. Driver (Controlador): Componente electrónico (en este caso, un TB6600) que interpreta las señales de la placa principal y gestiona la energía que se envía a un motor paso a paso (stepper).
Ender: Marca líder en impresiones 3D comerciales y domesticas. Feeder (Alimentador): Mecanismo con engranajes que empuja y tracciona el filamento hacia el hotend.
Firmware: El software de bajo nivel que se ejecuta en el microcontrolador (ESP32) y que controla todas las funciones de la máquina: lee los sensores, controla los motores, la temperatura, etc. Hotend (Cabezal de Extrusión): El conjunto de piezas que se calienta para derretir el plástico. Incluye el bloque calefactor, el cartucho calefactor, el termistor y la boquilla.
MOSFET: Es un tipo de transistor que regula la corriente a través de la aplicación de un campo eléctrico generado por un voltaje en su puerta, actuando principalmente como interruptor o amplificador en dispositivos electrónicos de alta corriente.
PET (Tereftalato de polietileno): Un tipo de plástico muy común, utilizado en botellas de bebidas. Es conocido por su resistencia y claridad.
PID (Control Proporcional Integral Derivativo): Un algoritmo de control inteligente que utiliza el firmware para mantener la temperatura de la boquilla lo más estable posible, minimizando las fluctuaciones.
PP (Polipropileno): Un polímero termoplástico versátil, conocido por su resistencia química, flexibilidad y bajo peso.
Stepper (Motor Paso a Paso): Un tipo de motor eléctrico que gira en pequeños incrementos o "pasos"

, permitiendo un control muy preciso del movimiento, ideal para la extrusión.
Termistor: Un sensor de temperatura cuya resistencia eléctrica varía con la temperatura. Es el componente que le "dice" al firmware qué tan caliente está el hotend.

# Anexo F: Archivos STL

Este anexo contiene la lista de todas las piezas personalizadas que deben ser impresas en 3D para el ensamblaje de la Extrusora D75. La fabricación aditiva permite que cualquier usuario pueda replicar, reparar o modificar los componentes de la máquina fácilmente.

Para asegurar la resistencia mecánica y la correcta funcionalidad de las piezas, se recomienda utilizar los siguientes parámetros como punto de partida. El material sugerido es PETG debido a su mayor resistencia térmica y durabilidad en comparación con el PLA, aunque un PLA+ de buena calidad también podría ser una alternativa viable.

Altura de capa: 0.2 mm - 0.28 mm
Relleno (Infill): 30% - 50% (Patrón cúbico o giroidal)
Perímetros (Paredes): 3 - 4
Soportes: Sí
Adhesión: Raft

Todos los archivos STL necesarios para la fabricación de la máquina están disponibles para su descarga. Escanee el siguiente código QR o visite el enlace para acceder al repositorio del proyecto.

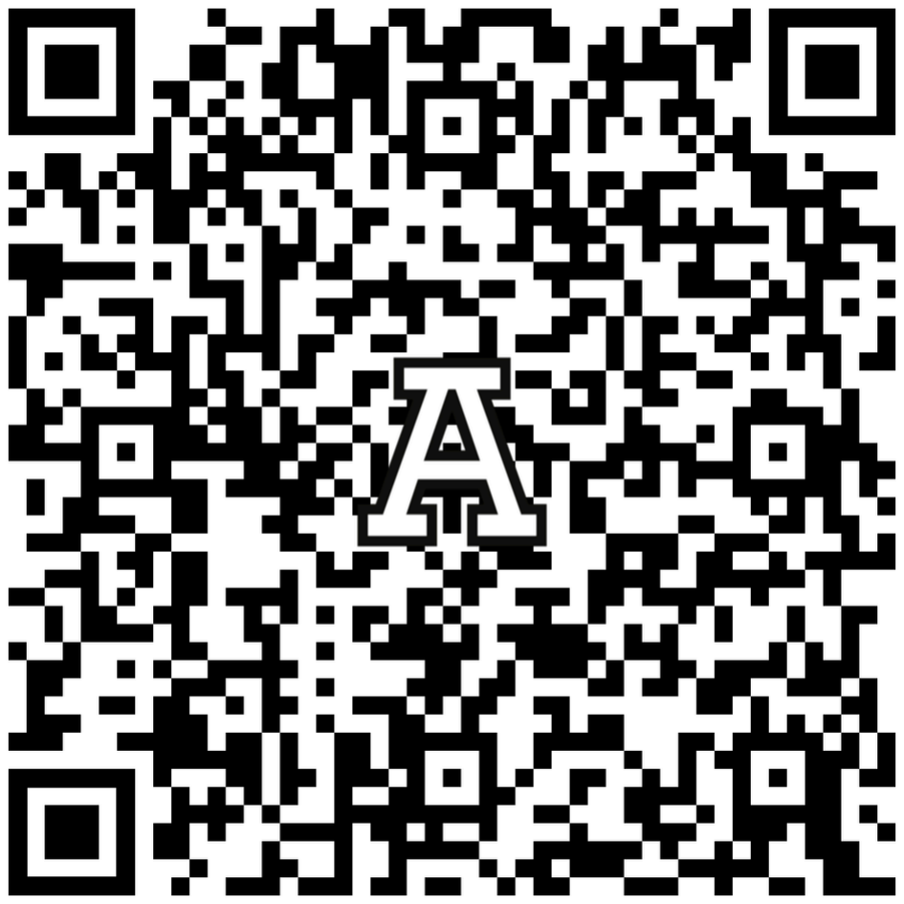
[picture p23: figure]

# O ingresa a

# PRACTICUM 2025 INGENIERÍA MECATRÓNICA 2025

# EXTRUSORA D75

# Versión 1.0 | Octubre 2025

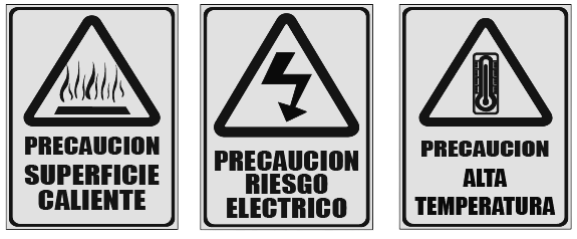
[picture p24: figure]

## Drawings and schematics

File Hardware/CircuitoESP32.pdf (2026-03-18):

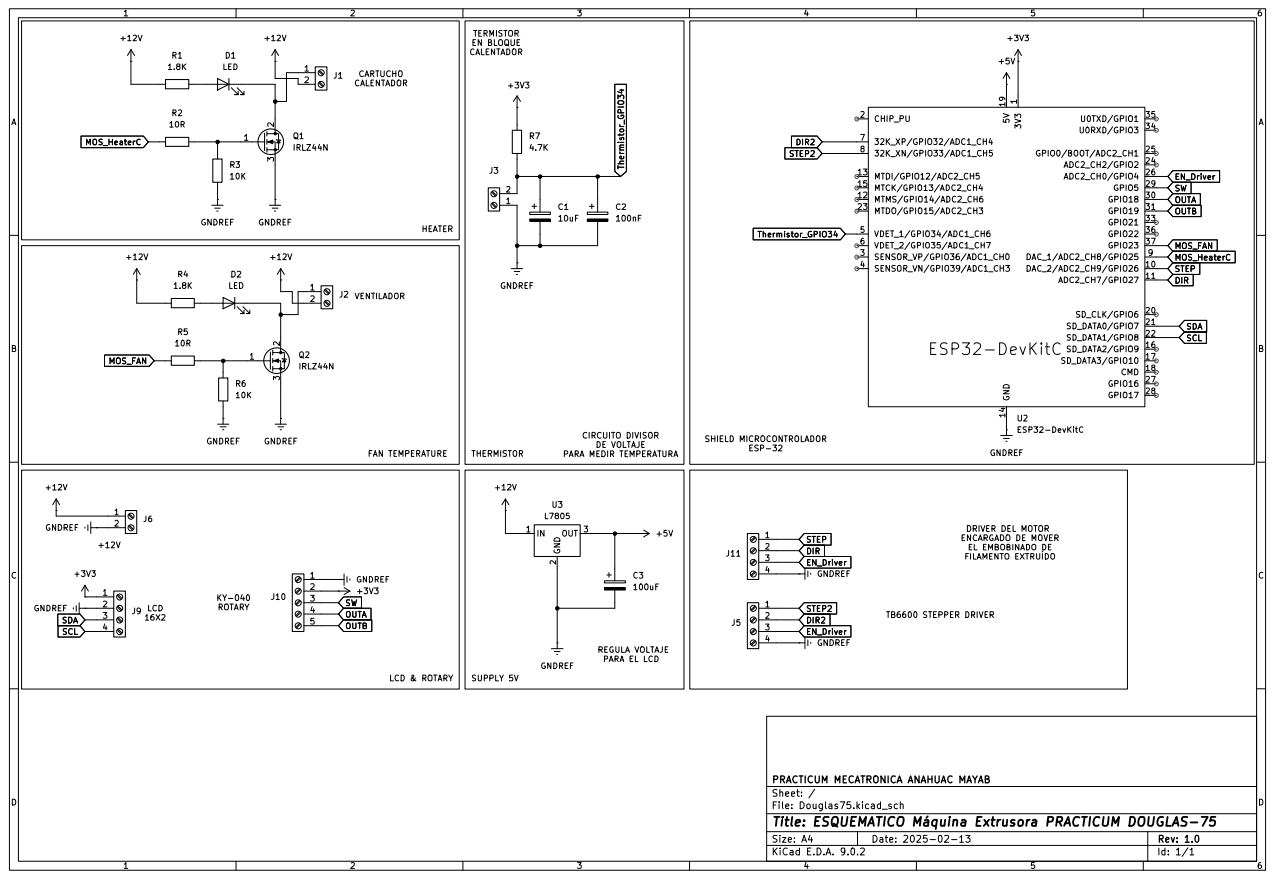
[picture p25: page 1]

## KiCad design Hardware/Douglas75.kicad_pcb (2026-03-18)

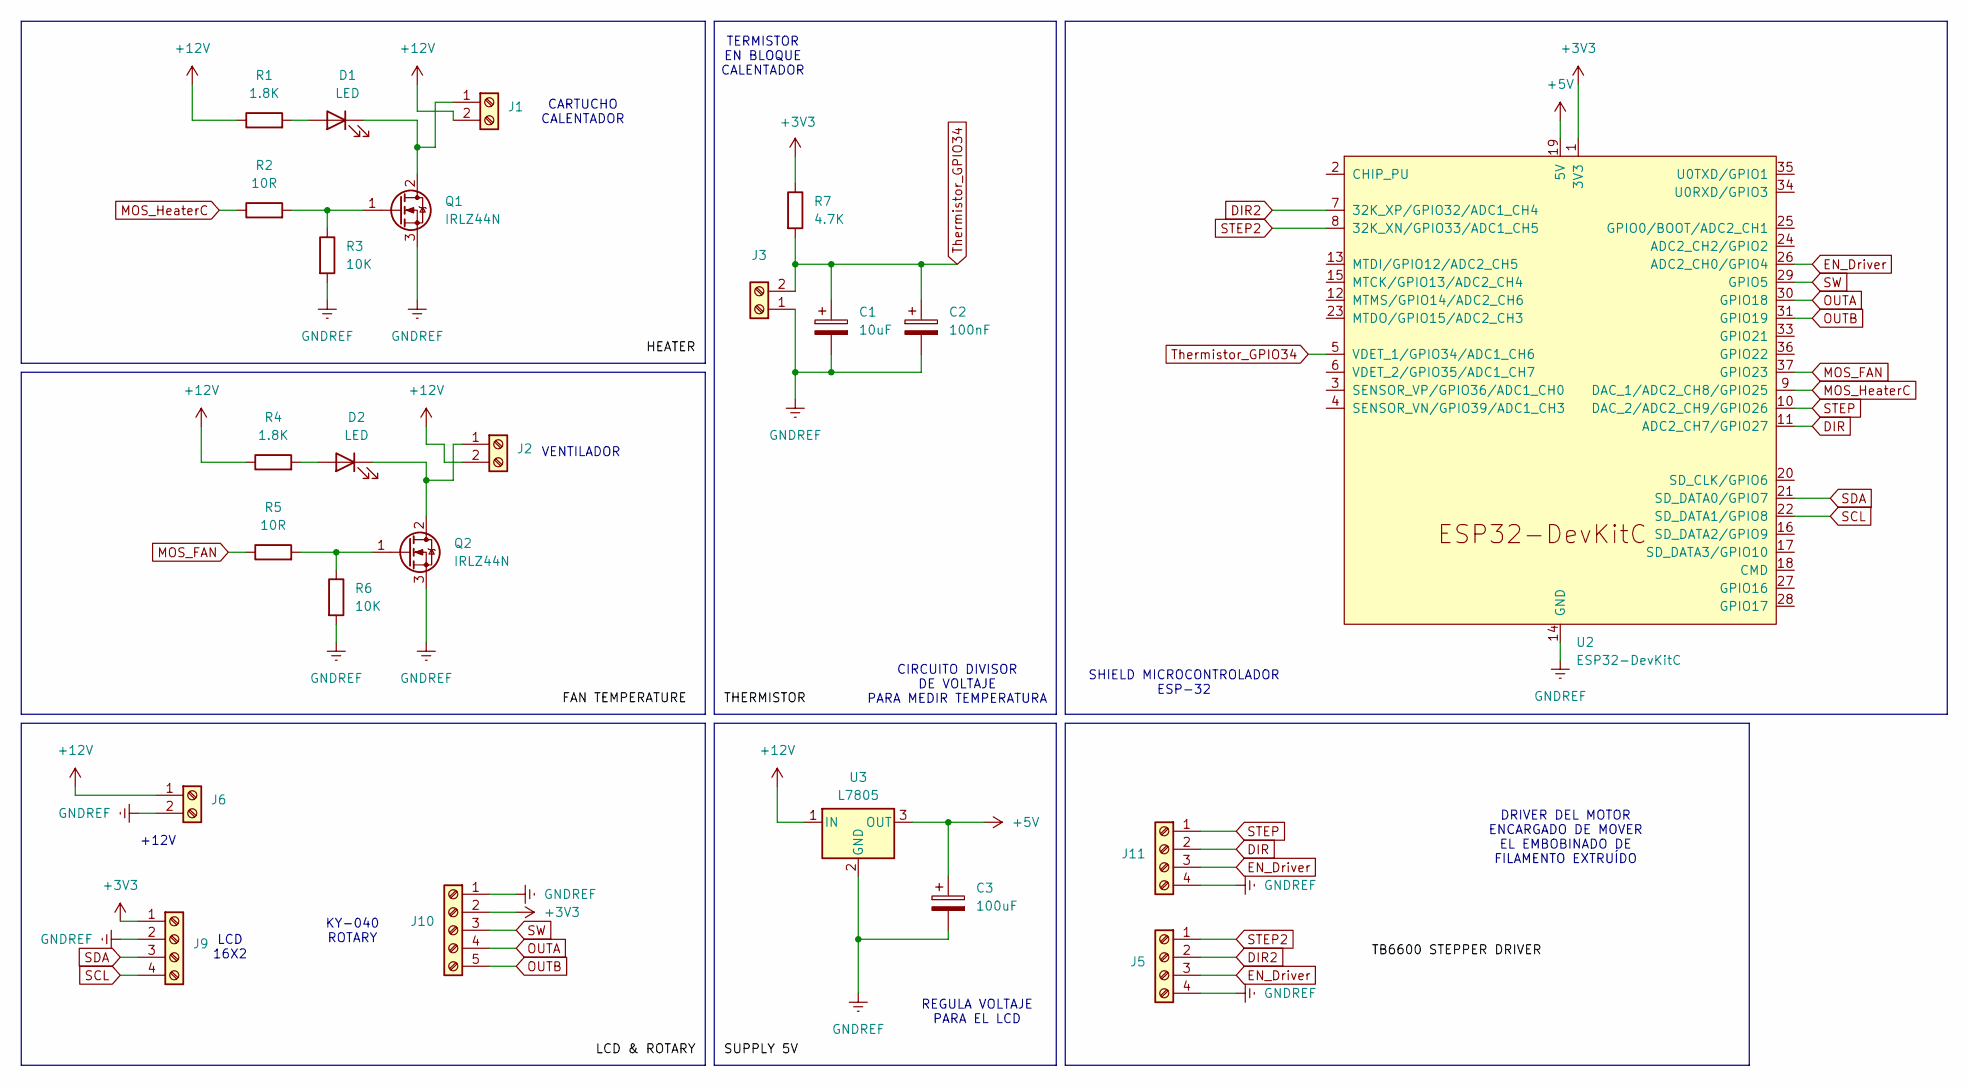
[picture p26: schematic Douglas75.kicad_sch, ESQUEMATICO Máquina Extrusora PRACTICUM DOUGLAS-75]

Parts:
C1: 10uF; CP_Radial_D4.0mm_P2.00mm
C2: 100nF; CP_Radial_D4.0mm_P2.00mm
C3: 100uF; CP_Radial_D5.0mm_P2.00mm
D1, D2: LED; LED_D5.0mm
J1, J2, J3, J6: TerminalBlock_Phoenix_MKDS-1,5-2-5.08_1x02_P5.08mm_Horizont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
J5, J9, J11: TerminalBlock_Phoenix_MKDS-1,5-4-5.08_1x04_P5.08mm_Horizont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
J10: TerminalBlock_Phoenix_MKDS-1,5-5-5.08_1x05_P5.08mm_Horizont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
Q1, Q2: IRLZ44N; TO-220-3_Vertical
R1, R4: 1.8K; R_Axial_DIN0309_L9.0mm_D3.2mm_P15.24mm_Horizontal
R2, R5: 10R; R_Axial_DIN0309_L9.0mm_D3.2mm_P15.24mm_Horizontal
R3, R6: 10K; R_Axial_DIN0309_L9.0mm_D3.2mm_P15.24mm_Horizontal
R7: 4.7K; R_Axial_DIN0309_L9.0mm_D3.2mm_P15.24mm_Horizontal
U2: ESP32-DevKitC
U3: L7805; TO-220-3_Vertical

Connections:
+3V3: J9.1, J10.2, R7.1, U2.1 (3V3)
+5V: C3.1, U2.19 (5V), U3.3 (OUT)
+12V: J1.2, J2.2, J6.1, R1.1, R4.1, U3.1 (IN)
DIR: J11.2, U2.11 (ADC2_CH7/GPIO27)
DIR2: J5.2, U2.7 (32K_XP/GPIO32/ADC1_CH4)
EN_Driver: J5.3, J11.3, U2.26 (ADC2_CH0/GPIO4)
GNDREF: C1.2, C2.2, C3.2, J3.1, J5.4, J6.2, J9.2, J10.1, J11.4, Q1.3 (S), Q2.3 (S), R3.2, R6.2, U2.14 (GND), U2.32 (GND), U2.38 (GND), U3.2 (GND)
MOS_FAN: R5.1, U2.37 (GPIO23)
MOS_HeaterC: R2.1, U2.9 (DAC_1/ADC2_CH8/GPIO25)
unnamed: D1.2 (A), R1.2
unnamed: D1.1 (K), J1.1, Q1.2 (D)
unnamed: D2.2 (A), R4.2
unnamed: D2.1 (K), J2.1, Q2.2 (D)
unnamed: Q1.1 (G), R2.2, R3.1
unnamed: Q2.1 (G), R5.2, R6.1
OUTA: J10.4, U2.30 (GPIO18)
OUTB: J10.5, U2.31 (GPIO19)
SCL: J9.4, U2.22 (SD_DATA1/GPIO8)
SDA: J9.3, U2.21 (SD_DATA0/GPIO7)
STEP: J11.1, U2.10 (DAC_2/ADC2_CH9/GPIO26)
STEP2: J5.1, U2.8 (32K_XN/GPIO33/ADC1_CH5)
SW: J10.3, U2.29 (GPIO5)
Thermistor_GPIO34: C1.1, C2.1, J3.2, R7.2, U2.5 (VDET_1/GPIO34/ADC1_CH6)

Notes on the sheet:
VENTILADOR
DRIVER DEL MOTOR ENCARGADO DE MOVER EL EMBOBINADO DE FILAMENTO EXTRUÍDO
SHIELD MICROCONTROLADOR ESP-32
KY-040 ROTARY
CIRCUITO DIVISOR DE VOLTAJE PARA MEDIR TEMPERATURA
CARTUCHO CALENTADOR
TERMISTOR EN BLOQUE CALENTADOR
REGULA VOLTAJE PARA EL LCD
+12V
LCD 16X2

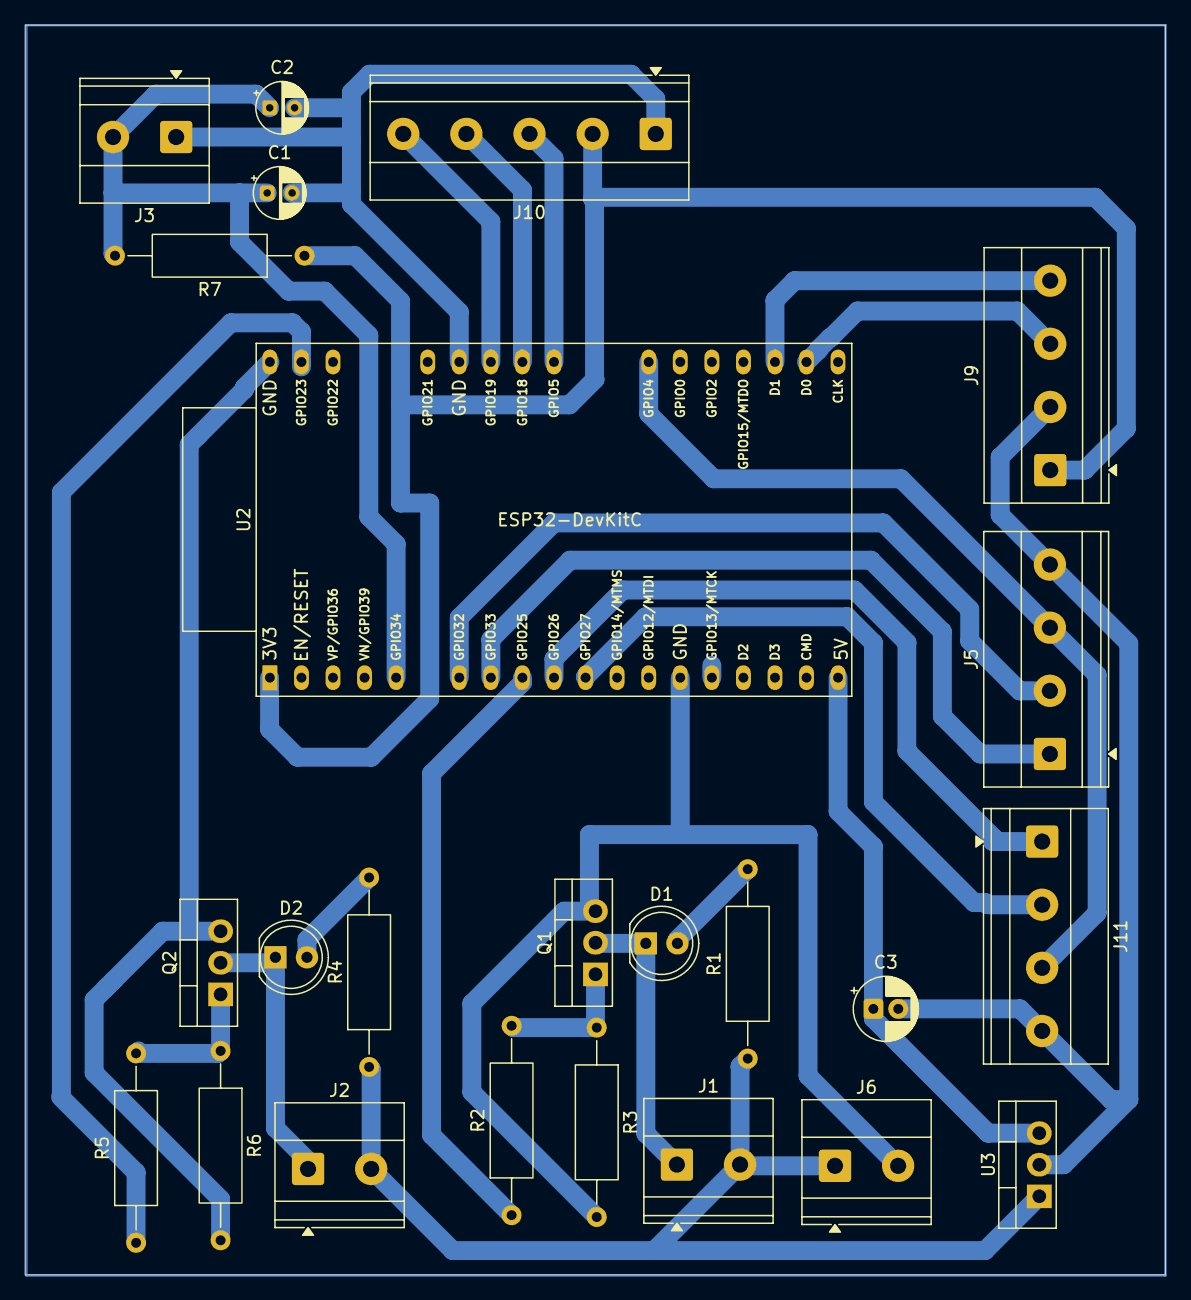
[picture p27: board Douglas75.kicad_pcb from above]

Board: 2 copper layers, 91.8 x 100.6 mm, 24 parts (0 on the bottom side), 23 nets.

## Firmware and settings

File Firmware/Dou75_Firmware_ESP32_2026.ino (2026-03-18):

// ═══════════════════════════════════════════════════════════════════
//  EXTRUSORA PP — ESP32 DualCore  ★  ESP32_Experimental
//  Convierte filamento PP 2.4 mm → 1.75 mm
//
//  Termistor: NTC 100K genérico Ender3 V1 (β = 3950)
//  Pantalla:  LCD I2C 20×4 @ 0x27
//  Encoder:   KY-040  (OUTA=18, OUTB=19, SW=5)
//
//  MAPA DE PINES FINAL
//  ┌──────────┬───────┬─────────────────────────────────────────┐
//  │ Señal    │ GPIO  │ Nota                                    │
//  ├──────────┼───────┼─────────────────────────────────────────┤
//  │ ENC_CLK  │  18   │ OUTA — interrupt                       │
//  │ ENC_DT   │  19   │ OUTB — interrupt                       │
//  │ ENC_SW   │   5   │ Botón encoder — INPUT_PULLUP            │
//  │ NTC      │  34   │ ADC1_CH6 — input-only, máx 3.3 V       │
//  │ HEATER   │  25   │ MOSFET calefactor — LEDC ch0            │
//  │ FAN      │  23   │ MOSFET ventilador — LEDC ch1            │
//  │ STEP1    │  26   │ Motor reductor STEP                     │
//  │ DIR1     │  27   │ Motor reductor DIR                      │
//  │ STEP2    │   4   │ Motor arrastre STEP                     │
//  │ DIR2     │   2   │ Motor arrastre DIR (TB6600 sin pull-up) │
//  │ EN_DRV   │  13   │ Enable ambos TB6600 (LOW=activo)        │
//  │ SDA      │  21   │ I2C default                             │
//  │ SCL      │  22   │ I2C default                             │
//  └──────────┴───────┴─────────────────────────────────────────┘
//
//  PROTOCOLO SERIAL (115200 baud)
//  ESP32 → PC  (cada 100 ms):
//    "T:160.5,S:160,D1:100,D2:100,P:127,F:64,RUN:1\n"
//  PC → ESP32:
//    "ST:165\n"   set temperatura
//    "SD1:100\n"  set RPM driver 1
//    "SD2:120\n"  set RPM driver 2
//    "SF:1\n"     fan AUTO=1 / OFF=0
//    "RUN\n"      iniciar extrusión
//    "STOP\n"     detener
//
//  LIBRERÍAS (Library Manager):
//    · RotaryEncoder     by Matthias Hertel
//    · PID_v1            by Brett Beauregard
//    · AccelStepper      by Mike McCauley
//    · LiquidCrystal_I2C by Frank de Brabander
// ═══════════════════════════════════════════════════════════════════

#include <Arduino.h>
#include <Wire.h>
#include <LiquidCrystal_I2C.h>
#include <PID_v1.h>
#include <AccelStepper.h>
#include <RotaryEncoder.h>

// ───────────────────────────────────────────────────────────────────
//  PINES
// ───────────────────────────────────────────────────────────────────
#define PIN_ENC_CLK   18
#define PIN_ENC_DT    19
#define PIN_ENC_SW     5
#define PIN_NTC       34
#define PIN_HEATER    25
#define PIN_FAN       23
#define PIN_STEP1     26
#define PIN_DIR1      27
#define PIN_STEP2      4
#define PIN_DIR2       2
#define PIN_EN_DRV    13

// ───────────────────────────────────────────────────────────────────
//  LEDC
// ───────────────────────────────────────────────────────────────────
#define LEDC_HEAT_CH  0
#define LEDC_FAN_CH   1
#define LEDC_FREQ  5000
#define LEDC_RES      8

// ───────────────────────────────────────────────────────────────────
//  NTC 100K — Ender3 V1 genérico  β = 3950
//  Divisor: 3.3 V → 4.7 KΩ → GPIO34 → NTC100K → GND
// ───────────────────────────────────────────────────────────────────
#define NTC_SERIES_R  4700.0f
#define NTC_R0      100000.0f
#define NTC_T0          25.0f
#define NTC_BETA      3950.0f
#define ADC_VREF         3.3f
#define ADC_MAX       4095.0f

// ───────────────────────────────────────────────────────────────────
//  MOTORES — Full step, 200 pasos/rev
//  pasos/seg = RPM × 200 / 60  →  1 RPM ≈ 3.333 pasos/seg
// ───────────────────────────────────────────────────────────────────
#define STEPS_PER_REV  200
#define RPM_TO_SPS     (STEPS_PER_REV / 60.0f)
#define MOTOR_DIR      -1      // -1 = invertir sentido; cambiar a 1 si gira al revés
#define RPM_MAX_LIM    300
#define RPM_DEFAULT    100

// ───────────────────────────────────────────────────────────────────
//  TEMPERATURA
// ───────────────────────────────────────────────────────────────────
#define TEMP_MIN        20
#define TEMP_MAX       260
#define TEMP_DEFAULT   160
#define TEMP_PREHEAT   150     // temperatura de pre-calentamiento
#define TEMP_READY_TOL   3.0f  // ±°C para considerar "temperatura lista"

// ───────────────────────────────────────────────────────────────────
//  MENÚ — estados de la máquina de estados HMI
// ───────────────────────────────────────────────────────────────────
enum MenuState : uint8_t {
  ST_MAIN,        // menú principal: PRE-CALENTAR / CONFIGURAR
  ST_PREHEAT,     // calentando hasta 150°C, espera temperatura
  ST_CONFIG,      // submenú configuración
  ST_EDIT_D1,     // editando RPM Driver 1
  ST_EDIT_D2,     // editando RPM Driver 2
  ST_EDIT_TEMP,   // editando temperatura setpoint
  ST_EDIT_FAN,    // editando Fan AUTO/OFF
  ST_RUNNING      // extrusión activa — pantalla de operación
};

// ───────────────────────────────────────────────────────────────────
//  OBJETOS
// ───────────────────────────────────────────────────────────────────
RotaryEncoder    encoder(PIN_ENC_DT, PIN_ENC_CLK, RotaryEncoder::LatchMode::FOUR3);
LiquidCrystal_I2C lcd(0x27, 20, 4);
AccelStepper     motor1(AccelStepper::DRIVER, PIN_STEP1, PIN_DIR1);
AccelStepper     motor2(AccelStepper::DRIVER, PIN_STEP2, PIN_DIR2);

// ───────────────────────────────────────────────────────────────────
//  VARIABLES COMPARTIDAS — protegidas con portMUX
// ───────────────────────────────────────────────────────────────────
portMUX_TYPE gMux = portMUX_INITIALIZER_UNLOCKED;

volatile double g_temp      = 0.0;
volatile int    g_setpoint  = TEMP_DEFAULT;
volatile int    g_rpmD1     = RPM_DEFAULT;
volatile int    g_rpmD2     = RPM_DEFAULT;
volatile int    g_heatPwm   = 0;
volatile int    g_fanPwm    = 0;
volatile bool   g_fanAuto   = true;     // true=AUTO, false=OFF
volatile bool   g_running   = false;
volatile bool   g_sensorOK  = true;
volatile bool   g_tempReady = false;    // true cuando T dentro de tolerancia

// ───────────────────────────────────────────────────────────────────
//  PID — solo Core 0
// ───────────────────────────────────────────────────────────────────
double pidIn = 0, pidOut = 0, pidSP = TEMP_DEFAULT;
PID myPID(&pidIn, &pidOut, &pidSP, 35.0, 0.5, 0.0, DIRECT);

// ═══════════════════════════════════════════════════════════════════
//  LECTURA NTC — promedio 8 muestras
// ═══════════════════════════════════════════════════════════════════
float readNTC() {
  long sum = 0;
  for (int i = 0; i < 8; i++) {
    sum += analogRead(PIN_NTC);
    delayMicroseconds(150);
  }
  float raw = sum / 8.0f;
  if (raw < 20 || raw > 4075) return -999.0f;
  float v    = raw * (ADC_VREF / ADC_MAX);
  float rNTC = NTC_SERIES_R * v / (ADC_VREF - v);
  float lnR  = logf(rNTC / NTC_R0);
  float invT = (1.0f / (NTC_T0 + 273.15f)) + (lnR / NTC_BETA);
  return (1.0f / invT) - 273.15f;
}

// ═══════════════════════════════════════════════════════════════════
//  TAREA CORE 0 — NTC + PID + Calefactor + Fan + Serial
// ═══════════════════════════════════════════════════════════════════
void taskPID(void* pv) {
  myPID.SetMode(AUTOMATIC);
  myPID.SetOutputLimits(0, 255);
  TickType_t wake = xTaskGetTickCount();

  for (;;) {
    float t = readNTC();
    bool  ok = (t > -100.0f);

    portENTER_CRITICAL(&gMux);
    pidSP = (double)g_setpoint;
    portEXIT_CRITICAL(&gMux);

    // ── Calefactor ──
    if (ok) {
      pidIn = (double)t;
      myPID.Compute();
      ledcWrite(LEDC_HEAT_CH, (uint32_t)pidOut);
    } else {
      pidOut = 0;
      ledcWrite(LEDC_HEAT_CH, 0);  // fallo sensor → apagar
    }

    // ── Ventilador AUTO: proporcional sobre 80°C ──
    int fanVal = 0;
    bool fanAuto;
    portENTER_CRITICAL(&gMux); fanAuto = g_fanAuto; portEXIT_CRITICAL(&gMux);
    if (fanAuto && ok && pidIn > 80.0) {
      fanVal = (int)constrain((pidIn - 80.0) * 2.55f, 0, 255);
    }
    ledcWrite(LEDC_FAN_CH, fanVal);

    // ── Temperatura lista ──
    bool ready = ok && fabsf(t - (float)pidSP) <= TEMP_READY_TOL;

    portENTER_CRITICAL(&gMux);
    g_temp      = ok ? (double)t : g_temp;
    g_heatPwm   = (int)pidOut;
    g_fanPwm    = fanVal;
    g_sensorOK  = ok;
    g_tempReady = ready;
    portEXIT_CRITICAL(&gMux);

    // ── Telemetría Serial ──
    if (ok) {
      Serial.printf("T:%.1f,S:%d,D1:%d,D2:%d,P:%d,F:%d,RUN:%d\n",
                    (float)pidIn, g_setpoint, g_rpmD1, g_rpmD2,
                    (int)pidOut, fanVal, (int)g_running);
    } else {
      Serial.println("T:ERR,S:0,D1:0,D2:0,P:0,F:0,RUN:0");
    }

    vTaskDelayUntil(&wake, pdMS_TO_TICKS(100));
  }
}

// ═══════════════════════════════════════════════════════════════════
//  HELPERS LCD — 20 caracteres exactos con relleno de espacios
// ═══════════════════════════════════════════════════════════════════
void lcdRow(uint8_t row, const char* fmt, ...) {
  char buf[21];
  va_list args;
  va_start(args, fmt);
  vsnprintf(buf, sizeof(buf), fmt, args);
  va_end(args);
  // Rellenar con espacios hasta 20 caracteres
  int len = strlen(buf);
  while (len < 20) buf[len++] = ' ';
  buf[20] = '\0';
  lcd.setCursor(0, row);
  lcd.print(buf);
}

void lcdClear4() {
  for (int i = 0; i < 4; i++) lcdRow(i, "");
}

// ═══════════════════════════════════════════════════════════════════
//  TAREA CORE 1 — HMI: encoder, menú, motores, comandos serial
// ═══════════════════════════════════════════════════════════════════
void taskHMI(void* pv) {

  // ── Estado HMI ──
  MenuState state     = ST_MAIN;
  int       menuSel   = 0;       // selección en menú actual
  int       cfgSel    = 0;       // selección en submenú config
  int       editVal   = 0;       // valor siendo editado
  int       lastEncPos= 0;
  bool      lastBtn   = HIGH;
  ulong     btnDown   = 0;
  bool      longFired = false;
  ulong     lastLcd   = 0;
  bool      dirty     = true;

  // ── Config items ──
  const char* cfgLabels[] = {
    "VELOCIDAD DRV 1",
    "VELOCIDAD DRV 2",
    "TEMPERATURA",
    "VENTILADOR"
  };
  const int CFG_N = 4;
  // cfgSel 0..3: primera visible en pantalla (scroll con 3 filas útiles)
  int cfgScroll = 0;

  // ── Motores ──
  motor1.setSpeed(0);
  motor2.setSpeed(0);
  digitalWrite(PIN_EN_DRV, HIGH);   // deshabilitado al inicio

  for (;;) {
    ulong now = millis();

    // ── Motores (siempre, no perder pasos) ──
    if (g_running) {
      motor1.runSpeed();
      motor2.runSpeed();
    }

    // ── Encoder tick ──
    encoder.tick();
    int encPos = (int)encoder.getPosition();
    int encDelta = encPos - lastEncPos;
    if (encDelta != 0) { lastEncPos = encPos; dirty = true; }

    // ── Botón: short press / long press ──
    bool btn = digitalRead(PIN_ENC_SW);
    bool shortPress = false, longPress = false;
    if (btn == LOW && lastBtn == HIGH) {          // flanco bajada
      btnDown = now; longFired = false;
    }
    if (btn == LOW && !longFired && (now - btnDown > 700)) {
      longPress = true; longFired = true; dirty = true;
    }
    if (btn == HIGH && lastBtn == LOW && !longFired) {
      shortPress = true; dirty = true;
    }
    lastBtn = btn;

    // ── Comandos desde Tkinter ──
    if (Serial.available()) {
      String cmd = Serial.readStringUntil('\n');
      cmd.trim();
      portENTER_CRITICAL(&gMux);
      if      (cmd.startsWith("ST:"))  g_setpoint = constrain(cmd.substring(3).toInt(), TEMP_MIN, TEMP_MAX);
      else if (cmd.startsWith("SD1:")) g_rpmD1 = constrain(cmd.substring(4).toInt(), 0, RPM_MAX_LIM);
      else if (cmd.startsWith("SD2:")) g_rpmD2 = constrain(cmd.substring(4).toInt(), 0, RPM_MAX_LIM);
      else if (cmd.startsWith("SF:"))  g_fanAuto = (cmd.substring(3).toInt() == 1);
      else if (cmd.startsWith("JOG1:")) {
        // Movimiento manual motor 1 (sin calentar)
        portEXIT_CRITICAL(&gMux);
        bool on = (cmd.substring(5).toInt() == 1);
        if (on) { motor1.setSpeed(MOTOR_DIR * g_rpmD1 * RPM_TO_SPS); digitalWrite(PIN_EN_DRV, LOW); }
        else    { motor1.setSpeed(0); if (!g_running && motor2.speed() == 0) digitalWrite(PIN_EN_DRV, HIGH); }
        goto skipMux;
      } else if (cmd.startsWith("JOG2:")) {
        portEXIT_CRITICAL(&gMux);
        bool on = (cmd.substring(5).toInt() == 1);
        if (on) { motor2.setSpeed(MOTOR_DIR * g_rpmD2 * RPM_TO_SPS); digitalWrite(PIN_EN_DRV, LOW); }
        else    { motor2.setSpeed(0); if (!g_running && motor1.speed() == 0) digitalWrite(PIN_EN_DRV, HIGH); }
        goto skipMux;
      } else if (cmd.startsWith("EN:")) {
        // Habilitar/deshabilitar AMBOS TB6600 (pin EN_DRV compartido)
        portEXIT_CRITICAL(&gMux);
        bool en = (cmd.substring(3).toInt() == 1);
        digitalWrite(PIN_EN_DRV, en ? LOW : HIGH);
        if (!en) { motor1.setSpeed(0); motor2.setSpeed(0); }
        else if (g_running) {
          motor1.setSpeed(MOTOR_DIR * g_rpmD1 * RPM_TO_SPS);
          motor2.setSpeed(MOTOR_DIR * g_rpmD2 * RPM_TO_SPS);
        }
        goto skipMux;
      }
      else if (cmd == "RUN") {
        g_running = true;
        portEXIT_CRITICAL(&gMux);
        float s1 = g_rpmD1 * RPM_TO_SPS, s2 = g_rpmD2 * RPM_TO_SPS;
        motor1.setSpeed(MOTOR_DIR * s1);
        motor2.setSpeed(MOTOR_DIR * s2);
        digitalWrite(PIN_EN_DRV, LOW);
        state = ST_RUNNING; dirty = true;
        goto skipMux;
      } else if (cmd == "STOP") {
        g_running = false;
        portEXIT_CRITICAL(&gMux);
        motor1.setSpeed(0); motor2.setSpeed(0);
        digitalWrite(PIN_EN_DRV, HIGH);
        state = ST_MAIN; menuSel = 0; dirty = true;
        goto skipMux;
      }
      portEXIT_CRITICAL(&gMux);
      dirty = true;
      skipMux:;
    }

    // ══════════════════════════════════════════════════════════
    //  MÁQUINA DE ESTADOS HMI
    // ══════════════════════════════════════════════════════════
    switch (state) {

      // ──────────────────────────────────────────────────────
      case ST_MAIN: {
        // Opciones: 0=PRE-CALENTAR, 1=CONFIGURAR
        if (encDelta) menuSel = constrain(menuSel + (encDelta > 0 ? 1 : -1), 0, 1);
        if (shortPress) {
          if (menuSel == 0) {
            // PRE-CALENTAR → 150°C
            portENTER_CRITICAL(&gMux); g_setpoint = TEMP_PREHEAT; portEXIT_CRITICAL(&gMux);
            state = ST_PREHEAT;
          } else {
            cfgSel = 0; cfgScroll = 0;
            state = ST_CONFIG;
          }
          dirty = true;
        }
        if (dirty && (now - lastLcd > 250)) {
          double t; bool sok;
          portENTER_CRITICAL(&gMux); t = g_temp; sok = g_sensorOK; portEXIT_CRITICAL(&gMux);
          lcdRow(0, "==== EXTRUSORA PP ===");
          lcdRow(1, "%s PRE-CALENTAR 150C", menuSel==0 ? ">" : " ");
          lcdRow(2, "%s CONFIGURAR",         menuSel==1 ? ">" : " ");
          if (sok) lcdRow(3, "T:%.1fC  SP:%dC", t, g_setpoint);
          else     lcdRow(3, "T: ERR  SP:%dC",  g_setpoint);
          lastLcd = now; dirty = false;
        }
        break;
      }

      // ──────────────────────────────────────────────────────
      case ST_PREHEAT: {
        // Esperar que llegue a TEMP_PREHEAT ± TOL
        bool ready;
        double t; bool sok;
        portENTER_CRITICAL(&gMux); t=g_temp; sok=g_sensorOK; ready=g_tempReady; portEXIT_CRITICAL(&gMux);

        if (!sok) {
          lcdRow(0, "!! ERROR SENSOR NTC !"); lcdRow(1, "Revisa conexion NTC ");
          lcdRow(2, "Calefactor apagado  "); lcdRow(3, "Long press = volver ");
        } else if (ready) {
          // Temperatura lista → auto-arrancar
          portENTER_CRITICAL(&gMux); g_running = true; portEXIT_CRITICAL(&gMux);
          float s1 = g_rpmD1*RPM_TO_SPS, s2 = g_rpmD2*RPM_TO_SPS;
          motor1.setSpeed(MOTOR_DIR*s1); motor2.setSpeed(MOTOR_DIR*s2);
          digitalWrite(PIN_EN_DRV, LOW);
          state = ST_RUNNING; dirty = true;
        } else {
          // Mostrando progreso de calentamiento
          if (dirty && (now - lastLcd > 500)) {
            int pct = (int)constrain((t / TEMP_PREHEAT) * 100.0, 0, 100);
            int bars = pct / 5;  // 0-20 barras en 20 chars
            char bar[21]; memset(bar, 0, 21);
            for (int i=0;i<20;i++) bar[i] = (i < bars) ? '#' : '-';
            lcdRow(0, "  PRE-CALENTANDO... ");
            lcdRow(1, "T:%.1fC  → %dC", t, TEMP_PREHEAT);
            lcdRow(2, "%s", bar);
            lcdRow(3, "%d%%  Long=Cancelar", pct);
            lastLcd = now; dirty = false;
          } else {
            dirty = true;  // forzar refresh periódico
          }
        }
        if (longPress) {
          // Cancelar
          portENTER_CRITICAL(&gMux); g_setpoint = TEMP_DEFAULT; portEXIT_CRITICAL(&gMux);
          state = ST_MAIN; menuSel = 0; lcdClear4(); dirty = true;
        }
        break;
      }

      // ──────────────────────────────────────────────────────
      case ST_CONFIG: {
        // Scroll: 3 filas útiles (fila 0 = header)
        if (encDelta) {
          cfgSel = constrain(cfgSel + (encDelta > 0 ? 1 : -1), 0, CFG_N-1);
          // Ajustar scroll para que cfgSel sea visible
          if (cfgSel < cfgScroll) cfgScroll = cfgSel;
          if (cfgSel >= cfgScroll + 3) cfgScroll = cfgSel - 2;
        }
        if (shortPress) {
          // Preparar valor de edición
          portENTER_CRITICAL(&gMux);
          if      (cfgSel==0) editVal = g_rpmD1;
          else if (cfgSel==1) editVal = g_rpmD2;
          else if (cfgSel==2) editVal = g_setpoint;
          else                editVal = g_fanAuto ? 1 : 0;
          portEXIT_CRITICAL(&gMux);
          state = (MenuState)(ST_EDIT_D1 + cfgSel);
          lcdClear4(); dirty = true;
        }
        if (longPress) { state = ST_MAIN; menuSel = 1; lcdClear4(); dirty = true; }

        if (dirty && (now - lastLcd > 200)) {
          lcdRow(0, "==== CONFIGURACION ==");
          for (int r=0; r<3; r++) {
            int idx = cfgScroll + r;
            if (idx < CFG_N) lcdRow(r+1, "%s%-16s", (idx==cfgSel ? ">" : " "), cfgLabels[idx]);
            else              lcdRow(r+1, "");
          }
          lastLcd = now; dirty = false;
        }
        break;
      }

      // ──────────────────────────────────────────────────────
      case ST_EDIT_D1:
      case ST_EDIT_D2: {
        bool isD1 = (state == ST_EDIT_D1);
        if (encDelta) editVal = constrain(editVal + encDelta*10, 0, RPM_MAX_LIM);
        if (shortPress) {
          portENTER_CRITICAL(&gMux);
          if (isD1) g_rpmD1 = editVal; else g_rpmD2 = editVal;
          portEXIT_CRITICAL(&gMux);
          if (g_running) {
            float sps = editVal * RPM_TO_SPS;
            if (isD1) motor1.setSpeed(MOTOR_DIR*sps);
            else      motor2.setSpeed(MOTOR_DIR*sps);
          }
          state = ST_CONFIG; lcdClear4(); dirty = true;
        }
        if (longPress) { state = ST_CONFIG; lcdClear4(); dirty = true; }
        if (dirty && (now - lastLcd > 100)) {
          lcdRow(0, isD1 ? "  VELOCIDAD DRV 1   " : "  VELOCIDAD DRV 2   ");
          lcdRow(1, "");
          lcdRow(2, "    < %d RPM >", editVal);
          lcdRow(3, " [OK]=Guardar Lng=X ");
          lastLcd = now; dirty = false;
        }
        break;
      }

      // ──────────────────────────────────────────────────────
      case ST_EDIT_TEMP: {
        if (encDelta) editVal = constrain(editVal + encDelta, TEMP_MIN, TEMP_MAX);
        if (shortPress) {
          portENTER_CRITICAL(&gMux); g_setpoint = editVal; portEXIT_CRITICAL(&gMux);
          state = ST_CONFIG; lcdClear4(); dirty = true;
        }
        if (longPress) { state = ST_CONFIG; lcdClear4(); dirty = true; }
        if (dirty && (now - lastLcd > 100)) {
          lcdRow(0, "    TEMPERATURA     ");
          lcdRow(1, "");
          lcdRow(2, "     < %d C >", editVal);
          lcdRow(3, " [OK]=Guardar Lng=X ");
          lastLcd = now; dirty = false;
        }
        break;
      }

      // ──────────────────────────────────────────────────────
      case ST_EDIT_FAN: {
        if (encDelta) editVal = (editVal == 0) ? 1 : 0;
        if (shortPress) {
          portENTER_CRITICAL(&gMux); g_fanAuto = (editVal == 1); portEXIT_CRITICAL(&gMux);
          state = ST_CONFIG; lcdClear4(); dirty = true;
        }
        if (longPress) { state = ST_CONFIG; lcdClear4(); dirty = true; }
        if (dirty && (now - lastLcd > 100)) {
          lcdRow(0, "    VENTILADOR      ");
          lcdRow(1, "");
          lcdRow(2, "   < %s >", editVal ? " AUTO " : " OFF  ");
          lcdRow(3, " [OK]=Guardar Lng=X ");
          lastLcd = now; dirty = false;
        }
        break;
      }

      // ──────────────────────────────────────────────────────
      case ST_RUNNING: {
        // Encoder ajusta setpoint de temperatura
        if (encDelta) {
          portENTER_CRITICAL(&gMux);
          g_setpoint = constrain(g_setpoint + encDelta, TEMP_MIN, TEMP_MAX);
          portEXIT_CRITICAL(&gMux);
        }
        // Long press = STOP
        if (longPress) {
          portENTER_CRITICAL(&gMux); g_running = false; portEXIT_CRITICAL(&gMux);
          motor1.setSpeed(0); motor2.setSpeed(0);
          digitalWrite(PIN_EN_DRV, HIGH);
          state = ST_MAIN; menuSel = 0; lcdClear4(); dirty = true;
        }
        if (dirty && (now - lastLcd > 500)) {
          double t; int sp, d1, d2, pwm, fpwm; bool sok, fan;
          portENTER_CRITICAL(&gMux);
          t=g_temp; sp=g_setpoint; d1=g_rpmD1; d2=g_rpmD2;
          pwm=g_heatPwm; fpwm=g_fanPwm; sok=g_sensorOK; fan=g_fanAuto;
          portEXIT_CRITICAL(&gMux);

          if (sok) lcdRow(0, "T:%.1fC   SP:%dC", t, sp);
          else     lcdRow(0, "T: ERR   SP:%dC",  sp);
          lcdRow(1, "D1:%dRPM  D2:%dRPM", d1, d2);
          lcdRow(2, "PWM:%-3d  FAN:%s", pwm, fan ? "AUTO" : "OFF ");
          lcdRow(3, "CORRIENDO Lng=STOP  ");
          lastLcd = now; dirty = false;
        } else {
          dirty = true;  // refrescar periódicamente
        }
        break;
      }
    } // switch

    taskYIELD();
  }
}
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
void loop() { vTaskDelete(NULL); }

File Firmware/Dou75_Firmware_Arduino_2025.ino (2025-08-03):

#include <RotaryEncoder.h>
#include <PID_v1.h>
#include <AccelStepper.h>
#include <LiquidCrystal_I2C.h>
#include <Wire.h>

#define ENCODER_USE_INTERRUPTS
#define ENCODER_OPTIMIZE_INTERRUPTS

// Pines
#define ENCODER_CLK 2
#define ENCODER_DT 3
#define ENCODER_SW 4
#define SENSOR_PIN A0
#define HEATER_PIN 9

#define dirPin 5
#define stepPin 6
#define dir2Pin 10
#define step2Pin 11

AccelStepper stepper1(AccelStepper::DRIVER, stepPin, dirPin);
AccelStepper stepper2(AccelStepper::DRIVER, step2Pin, dir2Pin);

LiquidCrystal_I2C lcd(0x27, 16, 2);
unsigned long lastLcdUpdate = 0;
const unsigned long lcdUpdateInterval = 1000; // 1 segundo

// Encoder
RotaryEncoder encoder(ENCODER_DT, ENCODER_CLK, RotaryEncoder::LatchMode::FOUR3);
int lastButtonState = HIGH;
int lastPos = 0;
bool settingTemp = true;

// Variables principales
double temp = 0;
int targetTemp = 160;
int rpm = 100;

// PID
double inputTemp, outputPWM, setpointTemp = 160;
double Kp = 35.0, Ki = 0.5, Kd = 0.0;
PID myPID(&inputTemp, &outputPWM, &setpointTemp, Kp, Ki, Kd, DIRECT);

// Debounce
unsigned long lastDebounceTime = 0;
const unsigned long debounceDelay = 200;

// Buffers para detectar cambios
double lastTemp = -1.0;
int lastTargetTemp = -1;
int lastRpm = -1;
bool lastSettingTemp = true;

// Mapeo temperatura-voltaje
float temps[] = {
  20, 110, 115, 120, 125, 130, 135, 140, 145,
  150, 155, 160, 165, 170, 175, 180, 185, 
  190, 195, 200, 205, 210, 215, 220, 225, 230
};

float voltages[] = {
  3.30, 2.94, 2.92, 2.89, 2.87, 2.85, 2.83, 2.79, 2.76,
  2.70, 2.63, 2.39, 2.19, 1.96, 1.79, 1.61, 1.45,
  1.31, 1.20, 1.07, 0.97, 0.88, 0.79, 0.72, 0.65, 0.59
};

float voltageToTemperature(float voltage) {
  int numPoints = sizeof(temps) / sizeof(temps[0]);
  for (int i = 0; i < numPoints - 1; i++) {
    if (voltage <= voltages[i] && voltage >= voltages[i + 1]) {
      float slope = (temps[i + 1] - temps[i]) / (voltages[i + 1] - voltages[i]);
      return temps[i] + slope * (voltage - voltages[i]);
    }
  }
  return temps[numPoints - 1];
}

void setup() {
  Serial.begin(115200);          // Serial rápido
  Wire.begin();
  Wire.setClock(400000);         // I2C a 400kHz para acelerar LCD

  attachInterrupt(digitalPinToInterrupt(ENCODER_DT), checkEncoder, CHANGE);
  attachInterrupt(digitalPinToInterrupt(ENCODER_CLK), checkEncoder, CHANGE);

  pinMode(stepPin, OUTPUT);
  pinMode(dirPin, OUTPUT);

  stepper1.setMaxSpeed(2000);
  stepper2.setMaxSpeed(2000);

  pinMode(ENCODER_SW, INPUT_PULLUP);
  pinMode(HEATER_PIN, OUTPUT);

  encoder.setPosition(0);

  myPID.SetMode(AUTOMATIC);
  myPID.SetOutputLimits(0, 255);

  lcd.init();
  lcd.backlight();
  lcd.clear();
  lcd.setCursor(0, 0);
  lcd.print("Extrusora Init OK");
  delay(1000);
  lcd.clear();
}

void loop() {
  checkEncoder();
  stepper1.setSpeed(-300);
  stepper1.run();
  stepper2.setSpeed(-300);
  stepper2.run();

  int buttonState = digitalRead(ENCODER_SW);
  unsigned long currentTime = millis();
  if (buttonState == LOW && lastButtonState == HIGH && (currentTime - lastDebounceTime > debounceDelay)) {
    settingTemp = !settingTemp;
    Serial.print("Modo: ");
    Serial.println(settingTemp ? "Temperatura" : "RPM");
    lastDebounceTime = currentTime;
  }
  lastButtonState = buttonState;
  stepper1.run();
  // Leer posición del encoder
  int newPos = encoder.getPosition();
  if (newPos != lastPos) {
    int delta = newPos - lastPos;
    if (settingTemp) {
      targetTemp += delta;
      if (targetTemp < 0) targetTemp = 0;
    } else {
      rpm += delta * 10;
      if (rpm < 0) rpm = 0;
      // Aquí mover velocidad stepper si quieres
    }
    lastPos = newPos;
  }
  stepper1.run();
  // Leer voltaje y convertir a temperatura
  int rawADC = analogRead(SENSOR_PIN);
  float voltage = rawADC * (5.0 / 1023.0);
  temp = voltageToTemperature(voltage);
  inputTemp = temp;
  setpointTemp = targetTemp;

  // PID
  myPID.Compute();
  analogWrite(HEATER_PIN, (int)outputPWM);
  stepper1.run();
  if (currentTime - lastLcdUpdate >= lcdUpdateInterval) {
  bool changed = false;

  if (abs(temp - lastTemp) > 0.1) {
    lastTemp = temp;
    changed = true;
  }
  if (targetTemp != lastTargetTemp) {
    lastTargetTemp = targetTemp;
    changed = true;
  }
  if (rpm != lastRpm) {
    lastRpm = rpm;
    changed = true;
  }
  if (settingTemp != lastSettingTemp) {
    lastSettingTemp = settingTemp;
    changed = true;
  }

  if (changed) {
    // Evitar lcd.clear() para que no parpadee
    lcd.setCursor(0, 0);
    lcd.print("T:");
    lcd.print(temp, 1);
    lcd.print("C O:");
    lcd.print(targetTemp);
    lcd.print("C   ");  // Espacios para limpiar resto

    lcd.setCursor(0, 1);
    lcd.print(settingTemp ? "Modo:T " : "Modo:R ");
    lcd.print("RPM:");
    lcd.print(rpm);
    lcd.print("   ");  // Espacios para limpiar resto

    // Serial
    //Serial.print("Temp: ");
    Serial.print(temp, 1);
    Serial.print(", ");
    Serial.println(targetTemp);
    //Serial.print(" C | RPM: ");
    //Serial.println(rpm);
  }

  lastLcdUpdate = currentTime;
}
  checkEncoder();
  stepper1.run();
  stepper2.run();
}

void checkEncoder() {
  encoder.tick();  // obligatorio si usas interrupciones
}

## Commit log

2026-03-18 Add new firmware file for Dou75 Arduino
2026-03-18 Add firmware for ESP32 DualCore extruder control
2026-03-18 Revise README with project details and support info
    Updated project description and bill of materials format. Added support information and modified contributor details.
2026-03-18 Refactor MotorCard class and improve layout

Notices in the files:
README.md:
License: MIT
